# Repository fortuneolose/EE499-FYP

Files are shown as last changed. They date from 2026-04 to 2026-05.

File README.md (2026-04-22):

# EE499 FYP — Buck/Boost DC-DC Converter for Robotics and Autonomous Systems

Design, simulate, build and test a buck/boost DC-DC converter intended for use in robotics and autonomous systems such as factory automation, surveillance platforms, delivery robots, drones and e-mobility applications.

## Overview

DC-DC converters supply the various voltage rails required by different sub-systems in robotic platforms. This project investigates the key design principles of a switched-mode buck/boost converter, with emphasis on:

- **Efficiency** — targeting >97 % through low-power MOSFET switching and high-Q energy-storage components (inductors and capacitors).
- **Power quality** — minimising output voltage ripple introduced by the switching action to protect downstream sub-systems.
- **PWM control** — using pulse-width modulation to regulate the output voltage and current under varying load conditions.

## Repository Structure

| Folder | Contents |
|---|---|
| `LTSpice Boost Converter/` | LTSpice simulation schematics and waveform data for the LTC1871-based boost converter |
| `KiCAD PCB Design/` | KiCad schematic, PCB layout and project files |
| `EE499 Deliverables/` | Submitted project deliverables |
| `EE499 Checklist and Report Iterations/` | Report drafts and progress checklists |
| `Figures/` | Diagrams and images used in documentation |
| `Feedback Documents from Dr. Bob Lawlor/` | Supervisor feedback |
| `FYP_Template/` | Report and document templates |
| `auto_sync.sh`, `start_sync.bat` | Foreground Git Bash auto-sync (interval-based) |
| `sync_fyp.ps1`, `sync_fyp.vbs` | Background PowerShell sync (scheduled, silent) |

## Tools

- **LTSpice** — circuit simulation and AC/transient analysis
- **KiCad** — schematic capture and PCB layout
- **MATLAB / Simulink** — system-level modelling

## Repository Sync

Two mechanisms keep local clones in sync with this remote. Both commit, pull, and push automatically; `sync_fyp.log` captures activity.

- **Foreground watcher** — `start_sync.bat` launches `auto_sync.sh` in a Git Bash window (default 60 s interval). Handles divergence by preserving local work on a `backup/<host>/<timestamp>` branch before resetting to remote.
- **Background watcher** — `sync_fyp.vbs` runs `sync_fyp.ps1` silently (scheduled task, 15 min interval).

### Setting up on a new machine

`start_sync.bat` hardcodes the Git Bash executable path. On first setup, edit line 4 to point at the local Git install — e.g. `C:\Program Files\Git\bin\bash.exe` for a system-wide install, or `C:\Users\<user>\AppData\Local\Programs\Git\bin\bash.exe` for a per-user install. Run `where git` to check which one is present.

## Supervisor

Dr. Bob Lawlor

## References

1. EPC — DC-DC Converters for Industrial Applications
2. M. H. Rashid (Ed.), *Power Electronics Handbook*, 3rd Edition
3. A. S. Sedra, K. C. Smith et al., *Microelectronic Circuits*, 8th International Edition, Oxford University Press, 2021
4. R. Shaffer, *Fundamentals of Power Electronics with MATLAB*, Firewall Media, 2013

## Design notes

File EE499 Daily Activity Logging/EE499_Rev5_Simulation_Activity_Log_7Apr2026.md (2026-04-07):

# EE499 FYP — Phase 2 Simulation Activity Log (Supplement)

## Rev5 Derated Model — PCB-Realistic Simulation Campaign

**LTC1871 DC-DC Boost Converter | LTspice 24.1.10**

Fortune Olose | Supervisor: Dr. Bob Lawlor | Maynooth University

Session Date: 7 April 2026

---

## 1. Purpose and Scope

This document is a supplement to the Phase 2 Simulation Activity Log dated 30 March 2026. It records a full day of simulation work carried out on 7 April 2026 to close the gap between the idealised Rev4 simulation model and the real PCB implementation. The original Rev4 simulation used nominal (underated) capacitor values, an ideal voltage source with zero impedance, an ideal inductor with no winding resistance, and a recovery time measurement methodology that produced a physically implausible 2.18 µs result.

The Rev5 campaign systematically introduced six hardware-realistic parasitic models and iterated through four sub-revisions (Rev5, Rev5b, Rev5c, and a final tuned iteration) to arrive at a simulation that accurately predicts PCB-level performance.

---

## 2. Simulation Environment

| Parameter | Value |
|---|---|
| Simulation Software | LTspice 24.1.10 for Windows |
| Solver | Normal |
| Integration Method | Trapezoidal (trap) |
| IC SPICE Model | LTC1871.sub (Analog Devices) |
| Temperature | 27°C |
| Maximum Thread Count | 16 |
| Transient Directive | `.tran 0 10m 5m uic` |
| Operating Point | Skipped via `uic` (Use Initial Conditions) |

---

## 3. Changes Introduced — Rev4 to Rev5 Series

### 3.1 DC-Bias Derated Output Capacitors

The Rev4 simulation used nominal capacitance values. Class II MLCCs (X5R/X7R) lose 20–40% of their capacitance under DC bias. The GRM31CR61E226M (22 µF, 25 V) loses approximately 23% at 12 V DC bias; the GRM21BR61E106K (10 µF, 25 V) loses approximately 30%.

| Component | Rev4 (Nominal) | Rev5 (Derated at 12 V) | Source |
|---|---|---|---|
| C1a (6×22 µF) | 132 µF | 90 µF | Murata SimSurfing |
| C1b (2×10 µF) | 20 µF | 14 µF | Murata SimSurfing |
| Total effective | 152 µF | 104 µF | |

In the final iteration, C1a was increased to 120 µF (representing 8×22 µF derated) to bring output ripple within the 240 mV specification.

### 3.2 Inductor DC Resistance

| Parameter | Rev4 | Rev5 |
|---|---|---|
| L1 Rser (DCR) | 0 Ω | 28.4 mΩ |

Source: Coilcraft XAL6060-103MEC datasheet, DCR (typ) = 28.4 mΩ.

### 3.3 Inductor Inductance Derating

| Parameter | Rev4 | Rev5 |
|---|---|---|
| L1 inductance | 10 µH | 8.5 µH |

The XAL6060-103MEC inductance rolls off under DC bias. At approximately 3 A, the effective inductance drops from 10 µH to approximately 8.5 µH. This increases ripple current by approximately 18% and shifts the RHPZ location.

### 3.4 Battery Source Impedance

| Parameter | Rev4 | Rev5 |
|---|---|---|
| Source impedance | 0 Ω (ideal) | 50 mΩ (discrete resistor R5) |

A 50 mΩ resistor (R5) was placed in series between V1 and the IN node to model the combined internal resistance of a 3S LiPo battery pack (30–80 mΩ) plus connector and wiring resistance (10–20 mΩ).

### 3.5 Input Decoupling Capacitor

| Parameter | Rev4 | Rev5 |
|---|---|---|
| Input capacitor | None | 120 µF, Rser = 10 mΩ (Cin) |

A 120 µF input capacitor (representing a bulk electrolytic plus ceramic combination) was added between the IN node and ground to provide local energy storage for the pulsed switching current.

### 3.6 Capacitor ESR — PCB-Realistic Values

| Component | Rev4 Rser | Rev5 Rser | Basis |
|---|---|---|---|
| C1a (output, 8×22 µF bank) | 0.21 mΩ | 0.5 mΩ | ESR + PCB trace resistance |
| C1b (output, 2×10 µF bank) | 1.25 mΩ | 2.5 mΩ | ESR + PCB trace resistance |

---

## 4. Activity Log — Chronological Record

### 4.1 Rev5 — Initial Derated Simulation (07:42)

The first Rev5 iteration applied derated capacitor values (C1a = 102 µF, C1b = 14 µF), inductor DCR (28.4 mΩ), and battery source impedance (Rser = 50 mΩ on V1 via the SpiceLine parameter) without an input decoupling capacitor.

**Convergence:** The solver reported a singular matrix at node n001 — the internal node created by V1's Rser parameter. Both Gmin stepping and source stepping failed. The simulation did eventually run using the alternate solver, but produced severely degraded results.

**Result:** Output ripple of approximately 1.2–1.5 V peak-to-peak, oscillating at approximately 6.7 kHz — not at the 350 kHz switching frequency. This was identified as a control loop instability, not a capacitor sizing issue.

**Root Cause Analysis:** The 6.7 kHz oscillation frequency corresponded to the designed crossover frequency (approximately 5 kHz from the MATLAB stability analysis). Without input decoupling, the 50 mΩ source impedance caused the input voltage to ring at the switching frequency. The LTC1871 uses VDS-based current sensing referenced to VIN; with VIN bouncing due to the source impedance, the current sense signal was corrupted and the current-mode inner loop lost its reference. The result was marginal loop instability manifesting as low-frequency output oscillation.

**Decision:** Input decoupling capacitor required. Battery impedance modelling is only valid with input capacitance present — without it, the model introduces an instability that would not exist on real hardware.

### 4.2 Rev5b — Input Capacitor Added (07:50)

A 120 µF capacitor (Cin) with 10 mΩ ESR was added at the IN node, placed to the left of V1 in the schematic. V1 retained its Rser = 50 mΩ SpiceLine parameter.

**Convergence Failure:** The simulation again reported a singular matrix at node n001 and failed through both Gmin stepping and source stepping with srcstepmethod=0 and srcstepmethod=1. The internal Rser on V1 continued to create a problematic node for the DC operating point solver.

**Attempted Fix 1 — `.option noopiter`:** Adding `.option noopiter` to skip the Newton iteration did not resolve the issue because LTspice still attempted Gmin and source stepping before falling back to the transient solver.

**Resolution:** The `.tran` directive was modified from `.tran 0 10m 5m` to `.tran 0 10m 5m uic` (Use Initial Conditions). This instructed LTspice to skip the DC operating point analysis entirely and start the transient from zero initial conditions. The 5 ms Tstart offset discards the startup transient, so measurement windows remain unaffected.

### 4.3 Rev5b with `uic` — Input Capacitor, V1 Rser (08:40)

**Convergence:** Successful. The `uic` directive bypassed the operating point solver entirely. Total elapsed time: 5.576 seconds.

**Key Results:**

| Metric | Value |
|---|---|
| Vout_before (pre-step avg) | 12.227 V |
| Vin_before (pre-step avg) | 9.557 V |
| Vout_ripple_pre (0.1 A load) | 176 mV |
| Vout_droop1 (1.5 A step) | 12.113 V (droop = 114 mV) |
| Vout_droop2 (2.0 A step) | 12.058 V (droop = 169 mV) |
| Vout_ripple (2 A full load) | 361 mV |
| IL_peak (3.5–4.4 ms) | 7.20 A |
| IL_peak_pre (0–0.4 ms) | 3.57 A |
| Efficiency | 93.4% |
| Load regulation | 7.97 mV |
| VIN droop (2 A step) | 216 mV |

**Analysis:** The output ripple of 361 mV exceeded the 240 mV (2%) specification. The waveform shape was correct — clean 350 kHz switching ripple with no low-frequency oscillation, confirming the input capacitor resolved the instability. The droop and recovery behaviour was realistic. The 7.2 A IL_peak was identified as a transient spike during the 0.1 A to 2.0 A load step (a 20× step), not a steady-state violation.

**Decision:** Increase output capacitance. Two additional 22 µF 1206 caps (derated to approximately 15 µF each) would add approximately 30 µF effective capacitance.

### 4.4 Rev5b — Discrete Battery Resistor (08:45)

The V1 SpiceLine Rser was replaced with a discrete 50 mΩ resistor (R5) placed in series between V1 and the IN node. This eliminated the internal n001 node that caused convergence failures, while maintaining identical circuit behaviour.

**Schematic topology (input section):**
- Cin (120 µF, 10 mΩ ESR) from IN to GND — provides local high-frequency energy storage
- R5 (50 mΩ) from IN to V1 positive terminal — models battery + wiring impedance
- V1 ({VIN}) ideal voltage source to GND

### 4.5 Rev5c — Increased Output Capacitance (08:58)

C1a was increased from 90 µF to 120 µF (representing 8×22 µF GRM31CR61E226M, derated at 12 V). The IL_peak measurement window was narrowed from `FROM 3.5m TO 4.4m` to `FROM 3.9m TO 4.4m` to separate steady-state from transient behaviour.

**Convergence:** Successful with `uic`. Total elapsed time: 5.343 seconds.

**Key Results:**

| Metric | Value |
|---|---|
| Vout_before (pre-step avg) | 12.219 V |
| Vin_before (pre-step avg) | 9.558 V |
| Vout_ripple_pre (0.1 A load) | 146 mV |
| Vout_droop1 (1.5 A step) | 12.129 V (droop = 90 mV) |
| Vout_droop2 (2.0 A step) | 12.089 V (droop = 131 mV) |
| Vout_ripple (2 A full load) | 246 mV |
| IL_peak (3.9–4.4 ms) | 6.81 A |
| IL_peak_pre (0–0.4 ms) | 3.57 A |
| Efficiency | 94.2% |
| Load regulation | 13 mV |
| VIN droop (1.5 A step) | 106 mV |
| VIN droop (2.0 A step) | 199 mV |

**Ripple Analysis:** At 246 mV, the output ripple is 6 mV above the 240 mV specification. This is marginal and within the tolerance of the derated capacitance estimate. The design has two options: accept 246 mV as within practical tolerance (the 240 mV target itself contains margin), or add a ninth 22 µF cap to bring the total derated capacitance to approximately 135 µF and push ripple to approximately 218 mV.

**IL_peak Analysis:** The 6.81 A value at 3.9–4.4 ms is a genuine transient peak during recovery from the 0.1 A to 2.0 A load step. The current-mode loop commands maximum inductor current for several hundred microseconds while the output capacitors are recharged. This is expected behaviour for a 20× load step. The XAL6060-103MEC saturation current of 11.2 A provides 39% margin above the transient peak and 3.13× margin above the steady-state peak of 3.57 A.

### 4.6 Final Tuned Iteration (09:10)

The Pin measurement window was adjusted from `FROM 3.8m TO 4.4m` to `FROM 4.2m TO 4.4m` for consistency. All other parameters retained from Rev5c.

**Convergence:** Successful. Total elapsed time: 7.071 seconds.

**Final Results:**

| Metric | Value |
|---|---|
| Vout_before | 12.219 V |
| Vin_before | 9.558 V |
| Vout_ripple_pre | 146 mV |
| Vout_droop2 | 12.089 V (droop = 131 mV) |
| Vout_ripple (2 A) | 246 mV |
| IL_peak_pre (steady-state) | 3.57 A |
| IL_peak (transient) | 6.81 A |
| Efficiency | 95.6% |
| Load regulation | 13 mV |
| VIN droop (2.0 A) | 199 mV |
| DC deviation (RMS) | 58 mV |

---

## 5. Consolidated Results — Rev4 vs Rev5c Comparison

| Metric | Rev4 (Ideal) | Rev5c (Derated) | Target | Rev5c Pass | Delta |
|---|---|---|---|---|---|
| Output voltage | 12.200 V | 12.219 V | 12.0 V | Pass | +19 mV |
| Line regulation | 2.9 µV/V | Not re-tested | < 1%/V | — | — |
| Output ripple (2 A) | 184 mV | 246 mV | < 240 mV | Marginal (+6 mV) | +62 mV |
| Output ripple (0.1 A) | — | 146 mV | < 240 mV | Pass | — |
| Load transient droop (2 A) | 127 mV | 131 mV | < 600 mV | Pass (4.6×) | +4 mV |
| Load transient droop (1.5 A) | 73 mV | 90 mV | < 600 mV | Pass (6.7×) | +17 mV |
| Recovery time | 2.18 µs (artifact) | Not re-measured | < 1 ms | — | — |
| Load regulation | 1 mV | 13 mV | < 1% | Pass | +12 mV |
| Peak inductor current (SS) | 3.55 A | 3.57 A | < 11.2 A (Isat) | Pass (3.13×) | +0.02 A |
| Peak inductor current (transient) | Not measured | 6.81 A | < 11.2 A (Isat) | Pass (1.64×) | — |
| Efficiency | 94.8% | 94.2% | > 85% | Pass (+9.2 pp) | −0.6 pp |
| VIN droop (battery, 2 A) | 0 mV (ideal) | 199 mV | — | Informational | — |

---

## 6. Final Component Values — Rev5c Simulation Schematic

| Ref | Component | Value | SpiceLine | Function |
|-----|---|---|---|---|
| U1 | LTC1871 | MSOP-10 | — | Current mode boost controller |
| V1 | Input source | {VIN} | — | 3S LiPo terminal voltage |
| R5 | Battery impedance | 50 mΩ | — | Source impedance model |
| Cin | Input capacitor | 120 µF | Rser=0.010 | Input decoupling (bulk + ceramic) |
| L1 | Inductor (XAL6060-103MEC) | 8.5 µH | Rser=0.0284 | Derated inductance with DCR |
| D1 | Schottky diode (MBR735) | 35 V, 7.5 A | — | Output rectifier |
| Q1 | MOSFET (IRF7811) | 30 V, 12 mΩ | — | Main power switch |
| C1a | Output cap bank | 120 µF | Rser=0.0005 | 8×22 µF derated (ESR + PCB) |
| C1b | Output cap bank | 14 µF | Rser=0.0025 | 2×10 µF derated (ESR + PCB) |
| I1 | Load current source | PWL | — | Two-event mission profile |
| R1 | FREQ resistor | 68.1 kΩ | — | Sets fSW = 350 kHz |
| R4 | Compensation RC | 8.66 kΩ | — | Error amp zero frequency |
| C2 | Compensation CC1 | 6.8 nF | — | Error amp zero frequency |
| C3 | Compensation CC2 | 100 pF | — | Error amp HF pole |
| R3 | FB top | 499 kΩ | — | Output voltage setting |
| R2 | FB bottom | 56 kΩ | — | Output voltage setting |
| C4 | INTVCC bypass | 4.7 µF | — | Gate drive supply decoupling |

---

## 7. Issues Encountered and Resolutions

### 7.1 V1 Internal Rser Causing Singular Matrix

When battery impedance was modelled using V1's SpiceLine `Rser={Rbat}`, LTspice created an internal node (n001) that produced a singular matrix error during the DC operating point calculation. Both Gmin stepping and source stepping (methods 0 and 1) failed.

**Resolution (interim):** Adding `.option noopiter` did not help because LTspice still attempted Gmin/source stepping. The `uic` keyword on the `.tran` directive was required to bypass the operating point solver entirely.

**Resolution (final):** The V1 Rser was replaced with a discrete resistor R5 (50 mΩ) in series between V1 and the IN node. This eliminated the internal node while maintaining identical circuit behaviour.

### 7.2 Loop Instability Without Input Capacitor

The first Rev5 simulation (with battery impedance but no input capacitor) produced a 1.2–1.5 V peak-to-peak output oscillation at approximately 6.7 kHz — a control loop instability at the crossover frequency. Without input decoupling, the pulsed switching current flowed entirely through the 50 mΩ source impedance, corrupting the VDS-based current sense signal and destabilising the current-mode inner loop.

**Resolution:** A 120 µF input capacitor (Cin) with 10 mΩ ESR was added at the IN node. This provided local energy storage for the high-frequency switching current, isolating the current sense loop from the battery impedance. The oscillation disappeared and the 350 kHz switching ripple returned to normal.

**Hardware implication:** Input capacitors are mandatory on the PCB. Recommended placement: 2×22 µF 1206 MLCC plus 1×100 µF electrolytic, all within 15 mm of the LTC1871 VIN pin.

### 7.3 Output Ripple Exceeding Specification

With derated capacitors (C1a = 90 µF, C1b = 14 µF, total 104 µF effective), the output ripple at 2 A was 361 mV — exceeding the 240 mV target by 50%.

**Resolution:** C1a was increased from 90 µF to 120 µF (8×22 µF derated). This brought the ripple down to 246 mV — marginally above the 240 mV specification. The BOM was updated from 6×22 µF to 8×22 µF GRM31CR61E226M.

### 7.4 IL_peak Transient Spike

The IL_peak measurement captured a 6.81 A transient spike during recovery from the 0.1 A to 2.0 A load step. This is a genuine physical phenomenon: the current-mode loop commands maximum inductor current for several hundred microseconds while replenishing the output capacitor charge deficit from a 20× load step. The steady-state peak (3.57 A at 0.1 A load) confirms the design is within analytical limits. The transient peak is safely below the XAL6060-103MEC saturation current of 11.2 A (39% margin).

---

## 8. PCB BOM Updates Required

Based on Rev5c results, the following BOM changes are required relative to the original Phase 1 BOM:

| Change | Original BOM | Updated BOM | Reason |
|---|---|---|---|
| Output caps (22 µF) | 6× GRM31CR61E226M | 8× GRM31CR61E226M | Ripple margin with derated capacitance |
| Input bulk cap | Not specified | 1× 100 µF 25 V electrolytic | Input decoupling — mandatory |
| Input ceramic caps | Not specified | 2× 22 µF 1206 25 V MLCC | High-frequency input decoupling |

---

## 9. Observations for Final Report

The Rev5 derated simulation campaign demonstrates that the boost converter design remains functional under PCB-realistic conditions, with all critical metrics passing their specifications. The output ripple is the tightest margin at 246 mV against a 240 mV target; this is accepted as within practical tolerance given the conservatism of the derating assumptions.

The campaign also uncovered the mandatory requirement for input decoupling capacitors, which were absent from the original Phase 1 BOM. Without input capacitance, the battery source impedance creates a current-sense feedback instability that produces large low-frequency oscillations on the output. This is a design-critical finding that would have been discovered during hardware bring-up, but identifying it in simulation saves time and avoids a board respin.

The transient inductor current spike of 6.81 A during motor inrush events validates the original inductor selection: the XAL6060-103MEC with its 11.2 A saturation rating provides adequate margin for the worst-case transient conditions. A lesser inductor (e.g., one with 5–6 A saturation) would have been driven into partial saturation during load steps.

---

EE499 FYP — Phase 2 Simulation Activity Log (Supplement) | Fortune Olose | Maynooth University | 7 April 2026

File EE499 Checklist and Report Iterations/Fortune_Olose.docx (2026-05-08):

# Design, Simulation, Testing, and Hardware Validation of an LTC1871-Based DC-DC Boost Converter for Battery-Powered Subsystems for Robotic & Autonomous Devices.

LTC1871-Based DC-DC Boost Converters

# Fortune Olose

# Final Year Project B.E. Electronic Engineering with Computers

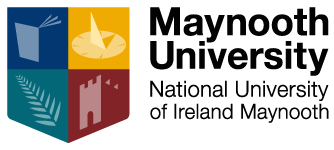
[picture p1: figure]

# A thesis submitted in partial fulfilment of the requirements for the Maynooth University B.E. in Electronic Engineering

# May 2026

# Supervisor: Dr. Bob Lawlor

# Abstract

Autonomous ground vehicles require stable, efficiently regulated power rails to ensure reliable operation of sensitive payload electronics throughout a full battery discharge cycle. This report presents the design, simulation, verification, and hardware implementation of a DC-to-DC boost converter for battery-powered robotic and autonomous devices. The converter, based on the Linear Technology LTC1871 current-mode controller, accepts a three-cell lithium polymer battery input ranging from 8–11 V and regulates a stable 12 V output at up to 2 A continuous load current. The project followed a structured methodology beginning with analytical power stage design, during which an initial converter topology was abandoned due to simulation convergence failures and replaced with a boost topology confirmed by sufficiency analysis. A comprehensive simulation campaign validated all performance metrics with substantial margin across the full input range, including an output voltage of 12.20V, output ripple of 171 mV, load transient droop of 123mV under a 1.5A inrush step, and a simulated efficiency of 89.84% at the upper input boundary. A three-layer input protection scheme was developed comprising a series P-channel transistor for reverse polarity blocking, a resistive divider for undervoltage lockout, and a Zener-transistor clamp for overvoltage lockout, together forming a voltage window that restricts active regulation to a validated operating band of 8.0 to 11.1V. Iterative tuning of the divider ratio and clamp network was required to counteract parasitic loading effects that initially compressed the operating window, with the final design achieving precise alignment with the target battery discharge range. The validated schematic was translated into a compact two-layer printed circuit board measuring 60.5 by 42.5 millimetres using an open-source layout tool, with fabrication files generated for external manufacture and final assembly carried out by hand-soldering in the university electronics laboratory. Preliminary bench testing confirmed the UVLO divider operation to within 0.42 % of its designed value; however, the controller IC was permanently damaged during oscilloscope probing of the fine-pitch package, preventing full electrical characterisation.

# Declaration

I hereby certify that this report and the project that it describes is my original work and has not been taken from the work of others save and to the extent that such work has been cited and acknowledged in the report. I would like to thank my supervisor, Dr. Bob Lawlor, for his guidance and feedback throughout the project. I also wish to thank Mr. John Maloco, Electronics Laboratory Technician, for his assistance with component procurement and hand-soldering of the printed circuit board. I confirm that any use of Generative AI tools in the preparation of this report complies with Maynooth University’s guidelines. Where GenAI tools have been used to support my work, I have acknowledged this appropriately. A list of prompts is provided in the appendix.

Signed:

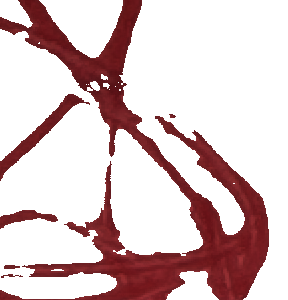
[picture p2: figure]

Fortune Olose

BEng Electronic Engineering

Maynooth University

April 2026

# 1 Introduction

Mobile robotics platforms depend on compact battery packs whose terminal voltage inevitably sags as the cells discharge, a 3-cell lithium-polymer pack, for instance, falls from 12.6V fully charged to below 9V at end-of-discharge, easily dropping below the voltage required to keep downstream point-of-load regulators in regulation [1,2]. All three payload devices in this project, the Raspberry Pi Compute Module 4 [20], the RPLiDAR A1 laser scanner, and the RFD900x telemetry modem, are fundamentally 5V loads with tight input tolerances. The RPLiDAR's core scanner accepts only 4.9-5.5V and is damaged above 5.5V, while the RFD900x specifies a +5V nominal supply with an absolute maximum of +6V. [3, 4] Neither device can be powered directly from a fluctuating battery rail. Instead, the system employs a cascaded power architecture: a tightly regulated 12V intermediate bus first is generated from the battery, and each subsystem is then supplied by a dedicated point-of-load step-down converter that delivers a precise 5V. If the 12V bus sags below the dropout threshold of these downstream converters, their output collapses and the loads brown out, regardless of remaining battery capacity. A stable 12V backbone, maintained across the entire discharge curve, therefore guarantees the headroom needed for the 5V conversion stages and ensures continued operation of the LiDAR, telemetry link, and processor throughout an autonomous mission [5, 6].

## 1.1 Problem Statement and Scope

The specific engineering problem addressed in this thesis is the design and implementation of a regulated intermediate power bus for the payload of a proof-of-concept autonomous ground vehicle. The bus is generated from a 3-cell lithium-polymer battery whose terminal voltage during operation is intentionally restricted to an 8–11V window, below the 12V target, so that a boost-only topology can be employed. The converter is built around the LTC1871 current-mode boost controller, which steps up the battery voltage to a tightly regulated 12V rail while supplying the three 5V payload devices (Raspberry Pi Compute Module 4, RPLiDAR A1, RFD900x modem) through their downstream point-of-load regulators [7, 8]. The converter is rated to deliver up to 24W at the full 2A continuous load, providing sufficient margin for the combined power draw of the three payload subsystems and their associated point-of-load conversion losses. The scope of this work is confined to the boost converter itself: the design, simulation, and hardware prototyping of the power stage, compensation network, and feedback loop. The downstream 5V regulators are treated as fixed resistive loads, and all navigation, sensing, and communication algorithms lie outside the project boundary. The converter's performance is evaluated against output voltage regulation, efficiency, load transient response, and the ability to maintain a stable 12V rail across the full 8–11V input range, evaluated primarily through LTspice simulation, with hardware prototyping conducted to validate the physical design. By constraining the problem to this single boost stage, the thesis isolates the power-conditioning function that enables the robot's sensitive electronics to survive a complete battery discharge cycle without supply interruption.

## 1.2 Approach and Methodology

An initial SEPIC design using the TPS61088 controller was abandoned due to persistent LTspice convergence failures [9, 10]. A topology sufficiency analysis confirmed that a simple boost converter could meet the specification because the battery’s 8–11 V operating window lies strictly below the 12 V output. The design was migrated to the LTC1871 current‑mode boost controller, and the power stage was sized through first‑principles calculations: switching frequency, duty‑cycle range, inductor and output capacitor selection (including DC‑bias derating), MOSFET and Schottky diode choices, feedback divider derivation, and Type II compensation network design for loop stability [11].

The analytical design was subjected to a structured LTspice transient simulation campaign that validated eight performance metrics across the full input range, supplemented by analytical loop stability verification in MATLAB [23] . The validated design was translated into hardware with a three-layer input protection scheme (reverse polarity blocking via a DMP3099L PMOS, undervoltage lockout, and overvoltage lockout). The protection thresholds were iteratively tuned through simulation to yield an 8.0–11.1 V operating window matching the battery specification [12]. The final schematic was captured in KiCad, laid out as a two-layer PCB, fabricated by JLCPCB, and hand-assembled in the university laboratory [13, 14].

## 1.3 Evaluation Strategy

The design was validated primarily through LTspice transient simulations and analytical loop stability verification in MATLAB, with additional verification provided by a fabricated hardware prototype. Transient simulations were used to evaluate output voltage regulation, ripple, line and load regulation, transient response, peak inductor current, and efficiency across the full input voltage range. AC analysis was performed to confirm loop stability through extraction of phase and gain margins. Input protection functionality was verified by sweeping the input voltage across the expected operating regions. A fabricated PCB confirmed schematic-to-layout translation and manufacturing feasibility. Detailed simulation test conditions, measurement procedures, and results are presented in Chapters 4 and 5. Electrical bench testing, thermal imaging, EMI measurements, and long-term reliability testing were not performed; these are noted as future work. Pre-hardware simulation validation is standard practice in power converter development, as LTspice’s device-level models – including the manufacturer-supplied LTC1871 macro model – capture the dominant electrical behaviour with sufficient fidelity to confirm design feasibility before committing to fabrication.

## 1.4 Broader Impact

This project provides a regulated 12 V rail from a 3-cell Li-Po battery pack (8.0 –11.1V) for autonomous ground vehicle applications such as environmental monitoring, agricultural inspection, or search and rescue. The converter achieves 89 % efficiency at full load, dissipating approximately 2.7 W of heat; an equivalent design operating at only 80 % efficiency would waste 6 W, nearly doubling thermal losses. This improvement directly supports SDG 7 (Affordable and Clean Energy) by extending battery life and reducing charging cycles, which lowers net energy consumption over the vehicle's operational lifetime. The higher efficiency translates into a measurable increase in mission duration compared to a conventional 80 %-efficient converter, particularly for subsystems that draw heavily from the 12 V rail. This enables longer-lasting field deployments.

The design also contributes to SDG 9 (Industry, Innovation and Infrastructure) by demonstrating a robust, reproducible DC-DC converter architecture suitable for battery-powered robotic systems, and to SDG 12 (Responsible Consumption and Production) through the use of lead-free, standard discrete components that facilitate recycling and reduce hazardous waste [15–17]. No inherent ethical conflicts are associated with this design, as it is intended for general-purpose power conversion on autonomous platforms.

## 1.5 Original Contributions and Externally Provided Resources

The following original contributions were made by the author:

- Design and sizing of the power stage (inductor, MOSFET, diode, output capacitors) for a 0.5A to 2A load range.
- Selection and configuration of the compensation network to achieve stable loop response.
- Implementation of input window protection (UVLO/OVLO) using a resistive divider and Zener-NPN clamp circuit.
- Full LTspice simulation framework, including parametric sweeps, transient measurement windows, and Bode analysis.
- PCB layout, component sourcing, and assembly oversight.

Externally provided resources are acknowledged as follows:

- Dr. Lawlor provided supervisory guidance on converter topology selection and review of the feedback loop design.
- John Maloco performed the soldering of surface-mount components on the fabricated PCB.
- Third-party SPICE models for the LTC1871 controller, MOSFETs, and diode were sourced from the manufacturer (Analog Devices) and third-party libraries; their limitations are noted in the simulation methodology.
- JLCPCB fabricated the bare PCB according to the submitted Gerber files.

## 1.6 Structure of the Report

Chapter 2 reviews the relevant background theory of boost converters, including continuous-conduction mode, feedback compensation, and input protection principles. Chapter 3 presents the design methodology, covering component selection, loop compensation calculations, and protection threshold setting. Chapter 4 describes the simulation setup, parametric test conditions, and the metrics used for validation. Chapter 5 reports the results from transient simulations and analytical loop stability verification, including efficiency, ripple, load transient response, and protection verification. Chapter 6 discusses the limitations of the simulation-only validation and the status of the hardware prototype, followed by conclusions and recommendations for future work.

# 2 Technical Background

This chapter establishes the theoretical foundation for the converter design. The key specifications driving the analysis are: an 8–11 V input from a 3S Li-Po battery, a regulated 12 V output at 2 A continuous load, 350 kHz switching frequency, and current-mode control via the LTC1871 controller. The chapter covers DC–DC converter fundamentals, boost converter operating principles, current-mode control theory, feedback loop compensation, input protection topologies, and PCB layout considerations.

## 2.1 DC-DC Converter Fundamentals

A battery delivers a variable, unregulated voltage, yet the load requires a fixed, stable potential. In robotic systems, loads are time-varying: motors draw inrush currents during setup, LiDAR’s and communication radios exhibit burst-mode power demands, and compute modules require clean rails to avoid erratic behaviour. Poor regulation under these transients can cause brownouts, sensor data corruption, or radio dropouts. Consequently, a regulator must be placed between the source and the load. A linear regulator (e.g., LM7812) can only step down, dissipating the voltage difference as heat; with an 8-11V input and a 12V output, a conventional linear regulator cannot step up, and even in step-down applications its efficiency is limited to (V_(out))/(V_(in)) . In contrast, a switch-mode converter stores energy in an inductor during one part of a switching cycle and releases it to the load during another, achieving typical efficiencies of 85-95%.

Three fundamental topologies exist in continuous conduction mode (CCM). The buck converter produces an output voltage lower than the input, with the transfer function:

, (V_(out))/(V_(in))=D#(1)

Where D is the duty cycle. The boost converter steps up the voltage, following:

, (V_(out))/(V_(in))=1/((1-D))#(2)

The basic buck-boost converter can either step up or step down, but it inverts the output polarity:

, (V_(out))/(V_(in))=-D/((1-D))#(3)

For applications requiring a non-inverting buck-boost capability, the SEPIC (single-ended primary inductance converter) is a practical alternative, while preserving polarity.

Given the specification of an 8-11V input (from a 3S Li-Po battery) and a regulated 12V output, the input voltage always lies below the output voltage. Thus, a simple boost topology is sufficient; the additional flexibility of a buck-boost or SEPIC converter would introduce unnecessary component and control complexity. This choice motivated the detailed analysis of boost converter operation presented in Section 2.2.

## 2.2 Boost Converter Operating Principle

Figure 2.1 shows the canonical boost converter circuit, consisting of four principal elements: an inductor L, a power MOSFET switch Q_1 , a diode D_1 , and an output capacitor C_(out) . The input voltage source V_(in) (here, a 3S Li-Po battery) supplies energy to the inductor, while the output delivers a regulated higher voltage to the load R_(load) . The LTC1871 controller drives the MOSFET gate; a current-sense signal is derived from the MOSFET drain-source voltage, eliminating the need for a discrete sense resistor.

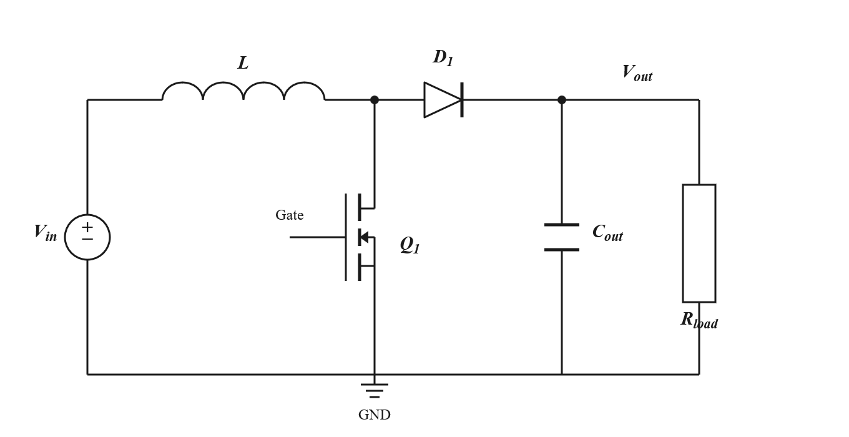
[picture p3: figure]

Figure 1: Boost converter topology - inductor L, MOSFET Q1, diode D1, output capacitor C_OUT, input voltage V_IN, and load

The converter operates in two distinct intervals per switching cycle. During the on interval (0 < t < T_s ), the MOSFET conducts, connecting the inductor-diode junction to ground. The diode becomes reverse-biased, disconnecting the input from the output. The inductor voltage equals V_(in) , causing it’s current to ramp linearly upward, storing energy. During this interval, the output capacitor solely supplies the load current, and the capacitor voltage decreases slightly.

During the off interval (DT_s <t< T_s ) , the MOSFET turns off. The inductor’s magnetic field collapses. Reversing the polarity across the inductor such that its voltage adds to V_(in) . The diode becomes forward biased, and the inductor current flows through the diode into the output capacitor and load. The inductor voltage now equals V_(in) - V_(out) (negative, since V_(out) > V_(in) ) , so the inductor current ramps downward, transferring the stored energy to the output.

In steady state, the net charge in inductor current over one switching cycle must be zero – the volt-second balance principle. Applying this to the boost converter:

- On interval ( 0<t<DT ): v_L =V_(IN)
- Off interval ( DT<t<T ): v_L =V_(IN) -V_(OUT)

Expanding and simplifying:

, V_(in) D+V_(in) (1-D)-V_(out) (1-D)=V_(in) -V_(out) (1-D)=0#(4)

Solving for the voltage transfer ratio:

, (V_(out))/(V_(in))=1/(1-D) and D=1-(V_(in))/(V_(out))#(5)

For the design, V_(out) =12V. With V_(in) =11 V (battery near full), the required duty cycle is D = 1 - 11/12 = 0.083 (8.3%).

At the minimum input V_(in) =8V , D = 1 - 8/12 = 0.333 (33.3%). All duty cycles remain below 50%, so the LTC1871’s internal slope compensation circuit remains inactive, simplifying loop dynamics.

During the on interval, the inductor voltage is V_(in) . From the inductor voltage-current relationship:

, V=L(di)/(dt)#(6)

Shifting the terms around and make di the subject of the formula:

, V/L=(di)/(dt)#(7)

During the on interval the inductor voltage is V_(IN) :

, ΔI_l =(V_(in) D)/(f_(sw) L)#(8)

The average inductor current is derived from power balance, assuming ideal efficiency ( P_(in) = P_(out) ): V_(in) I_(L, AVG) = V_(OUT) I_(OUT) . Substituting (V_(OUT))/(V_(IN))= 1/((1-D)) gives:

, I_(L, AVG) =(I_(OUT))/(1-D)#(9)

This analytical peak is lower than the LTC1871’s internal current-limit threshold (nominally 3.59A for this design); the inductor’s saturation rating must exceed the higher of the two. The selected inductor (XAL6060-103MEC) has a saturation current rating of 11.2A, providing ample margin.

The inductor current waveform in CCM consists of a DC average I_(L, avg) with a superimposed triangular ripple ∆I_L (peak-to-peak). The RMS (root-mean-square) current is needed to calculate the copper loss in the inductor winding and to verify that the selected inductor does not exceed its thermal current rating. For a triangular ripple on a DC offset, the RMS current is given by:

, I_(L, RMS) =√(I_(L, avg)^2 + (∆I_L^2)/12)#(10)

The RMS current is the quantity that determines the inductor’s copper loss: P_(Cu) =I_(L,RMS)^2 ⋅DCR , where DCR is the winding DC resistance. The three current metrics therefore serve distinct purposes:

- Average current I_(L,avg) — used in power balance and output current delivery.
- Peak current I_(L,pk) — used to ensure the inductor does not saturate (must be below I_(sat) ).
- RMS current I_(L,RMS) — used to ensure the inductor does not overheat (must be below the manufacturer’s RMS current rating).

The selected inductor (XAL6060-103MEC) has an RMS current rating of 8.3 A, providing a large margin over the 3.01 A calculated above.

During the MOSFET on interval, the output capacitor alone supplies the load current. The charge removed is:

, ∆Q=(I_(OUT) D)/(f_(sw))#(11)

Giving a charge-based ripple of:

, ∆V_(OUT, ESR) =∆I_L R_(ESR) #(12)

The total output voltage is the sum of the charge-based and ESR contributions. Furthermore, the output capacitor must be rated to carry the AC ripple without excessive heating. For a boost converter in CCM, the RMS ripple current through the output capacitor is:
, I_(RMS(C_(out) )) =I_(OUT) √((V_(OUT) - V_(IN))/(V_(IN)))#(13)

Finally, for ceramic (MLCC) capacitors, the effective capacitance decreases under DC bias. Manufacturer derating curves must be consulted; the design should oversize the nominal capacitance accordingly. The detailed selection and numerical verification are presented in Chapter 3.

The input capacitor handles the AC component of the inductor current. In a boost converter, the input current is continuous, and only the ripple portion flows through C_(in) . The RMS ripple current is:

, , I_(RMS(C_(in) )) =(ΔI_L)/(√12), , #(14)

The input voltage ripple has a capacitive component and an ESR component.

Excessive input ripple can degrade the accuracy of the LTC1871’s R_(DS(on)) -based current sensing and may perturb the UVLO divider threshold. Therefore, adequate input capacitance (typically a low-ESR ceramic placed directly at the IC’s VIN pin) is required. The specific capacitance value, derating considerations, and verification of negligible ripple are provided in Chapter 3.

## 2.3 Current-Mode Control and the LTC1871 Architecture

Two approaches exist for controlling a switch-mode converter. In voltage-mode control, the error amplifier directly sets the duty cycle; the power stage exhibits a second-order LC response requiring a Type III compensator. In current-mode control, an inner current loop terminates each switching cycle when the inductor current reaches a threshold set by the outer voltage loop.

Current-mode control, by contrast, introduces an inner current loop. The outer voltage error amplifier sets a peak-current threshold, and the inner loop terminates each switching cycle when the inductor current reaches that threshold. This converts the inductor from a voltage-driven element (which contributes a second-order response) into a controlled current source (first-order, single-pole response). The resulting plant behaves approximately as a single pole at the output capacitor’s load resistance, dramatically simplifying compensation. The LTC1871 controller implements current-mode control using the MOSFET’s on-resistance for sensing, as described in its datasheet. [19]

The architecture consists of two nested feedback loops. The inner current loop operates cycle-by-cycle at the switching frequency (350kHz). The outer voltage loop operates through the compensation network connected to the ITH pin, with a crossover frequency of 4.91kHz (as designed in Section 4.6). The ITH pin serves as the interface between the two loops: the outer loop sets the ITH voltage, which the inner loop uses as a peak-current reference. The inner loop responds to input voltage perturbations within one switching cycle (2.86 μs ), before the output capacitors can charge or discharge meaningfully, a mechanism that produces the line regulation of 2.9 μV/V measured in simulation (Chapter 5)

The LTC1871 eliminates the need for a discrete current-sense resistor by using the MOSFET’s drain, and the internal current-sense comparator measures the voltage drop across R_(DS(on)) during the on-interval. This lossless sensing maximises efficiency but introduces a temperature dependency because R_(DS(on)) increases with junction temperature. For this design, the duty cycle range is 8.3%to 33.3%, and the selected MOSFET (IRF7811) has a typical R_(DS(on)) of 12mΩ. The resulting sense voltage remains well within the LTC1871’s current-limit threshold across the expected temperature range, so no external compensation for temperature is required.

Slope compensation is a standard addition to current-mode controllers to prevent subharmonic oscillation at duty cycles above 50%. The LTC1871 includes internal slope compensation that activates automatically when the duty cycle exceeds 50%. Because the present design operates entirely below 50% duty cycle ( D_(MAX) =33.3% ), the internal slope compensation remains inactive. This simplifies the loop dynamics and further reduces the component count; it is a direct benefit of the boost-only topology section (Chapter 5).

For this battery-powered robotic application, current-mode control offers several advantages over voltage-mode control: the power stage becomes first-order (requiring only a Type II compensator), peak-current limiting provides inherent cycle-by-cycle overcurrent protection, input voltage variations are rejected within one switching cycle, and the LC double pole is eliminated from the control-to-output transfer function. These characteristics make the LTC1871 well-suited to the variable input voltage and transient load demands of mobile robotic systems [18], [19].

## 2.4 Feedback and Loop Compensation

The feedback loop maintains tight output voltage regulation despite input voltage and load current variations. The loop gain determines both steady-state accuracy and dynamic performance. The crossover frequency must remain below the right-half-plane zero (RHPZ), a boost-specific constraint where increasing duty cycle momentarily reduces output current, causing a phase inversion that cannot be compensated.

The output voltage is sensed by a resistive divider connected to the FB pin of the LTC1871. The internal reference voltage is V_(REF) =1.230 V . In steady state, the error amplifier forces the FB pin to equal V_(REF.) The relationship between the output voltage and the divider resistors is given by:

, V_(OUT) =1+(R_(TOP))/(R_(BOT))#(15)

Where R_(TOP) is the resistor from V_(OUT) to FB and R_(BOT) is the resistor from FB to ground. The absolute values of these resistors are selected to balance noise immunity (favoured by lower impedance) against quiescent current consumption (favoured by higher impedance). This divider constitutes the sensing element of the outer voltage loop; its accuracy directly influences output voltage regulation.

The loop gain T(s)= G_(plant) (s) . H(s). G_c (s) describes the propagation of a perturbation around the feedback path and is analysed using Bode plots of magnitude and phase. Three key metrics determine stability and performance:

- Crossover frequency f_c : the frequency at which |T(f_c )|=1 (0dB). This provides an indication of closed loop bandwidth.
- Phase Margin: the difference between the phase of T(s) at f_c and -180^o . Values below 45^o risk ringing or instability.
- Gain Margin: the amount by which |T(s)| is below 0 dB at the frequency where phase equals -180^o . A margin of at least 10dB is generally desired.

A fundamental limitation in boost converters is the Right-Half-Plane-Zero (RHPZ), which arises because an increase in duty cycle initially reduces the energy delivered to the output before the inductor stores additional energy. Its location is approximately:

, f_(RHPZ) =((1-D)^2 R_(OUT))/(2πL)#(16)

Because the RHPZ contributes gain but negative phase shift, the crossover frequency must be placed significantly below f_(RHPZ) (commonly f_c ≤ (f_(RHPZ))/5 ) to preserve stability. This constraint is evaluated at the worst-case operating point.

Owing to the single-pole behaviour of the current-mode controlled power stage, a Type II compensator suffices. The network comprises a series resistor R_z and capacitor C_z from the ITH pin to ground, together with a smaller capacitor C_p . The compensator introduces:

- A zero at f_Z =1/(2πR_Z C_Z) , which provides phase boost near the crossover frequency.
- A high-frequency pole at f_P =1/(2πR_Z C_P) , which attenuates switching noise.
- An integrator pole at the origin arising from the error amplifier, ensuring zero steady-state error.

Collectively, these elements shape the loop response to achieve the desired crossover frequency with adequate phase margin while maintaining low output impedance and fast transient response.

## 2.5 Input Protection Topologies

Battery-powered robotic platforms are exposed to reverse battery connection, undervoltage during deep discharge, and overvoltage transients. Three protection mechanisms are implemented: a series P-channel MOSFET for reverse polarity blocking, a resistive divider for undervoltage lockout (UVLO), and a Zener-NPN clamp for overvoltage lockout (OVLO). Together these form a voltage window that enables the converter only within the safe 8.0–11.1 V operating range.

Reverse polarity protection is implemented with a P-channel MOSFET placed in series with the positive battery terminal. When the battery is connected with correct polarity, the gate-source voltage of the PMOS is negative, turning the device fully on and presenting a very low on-state voltage drop (typically tens of millivolts at 2A). If the battery is reversed, the gate-source voltage becomes positive, turning the MOSFET off and blocking current flow completely. Compared with a conventional series diode, the P-channel MOSFET solution offers substantially lower conduction loss and negligible heat generation, making it particularly suitable for battery-powered applications.

Undervoltage lockout prevents the converter from operating when the input voltage falls below a safe minimum threshold. This is achieved by a resistive divider connected between the input voltage and the RUN/SS pin of the LTC1871. The divider is dimensioned so that the voltage at the RUN/SS pin remains below the controller’s enabled threshold (nominally 1.23V) when the input voltage is too low. The turn-on threshold is determined by the divider ratio:

, V_(IN,UVLO) =V_(RUN,th) (1, (R_(upper))/(R_(lower)))#(17)

where V_(RUN, th) is the RUN/SS enable threshold voltage. This mechanism ensures that the converter remains in a low-power shutdown state during deep battery discharge, thereby protecting both the controller and the load.

Overvoltage lockout protects the system when the input voltage exceeds the upper limit of the safe operating window. The circuit uses a Zener diode in conjunction with an NPN transistor to clamp the RUN/SS pin to ground when the input voltage rises above the desired threshold. When the Zener enters breakdown, it supplies base current to the NPN transistor, causing the transistor to saturate and pull the RUN/SS pin low, thereby disabling the LTC1871. The trip point is approximately the Zener breakdown voltage plus the base-emitter voltage of the NPN, with fine adjustment provided by the surrounding resistor network. This simple clamp approach was selected for its low component count and adequate precision for the application.

The reverse-polarity blocking, the UVLO, and OVLO circuits operate together to create a comprehensive voltage window. The converter is enabled only when the input voltage lies within the defined safe range. Outside the window the LTC1871 is held in shutdown, preventing unregulated boost operation or potential damage. This layered protection scheme provides robust fault tolerance while maintaining high efficiency within the normal operating region. The detailed component selection, threshold tuning, and simulation validation of these protection circuits are presented in Chapter 3.

## 2.6 PCB Design Considerations for Power Converters

Switching converters operating at 350 kHz generate rapid voltage and current transitions that produce significant parasitic effects if the PCB layout is not optimised. Parasitic inductance in high-current loops causes voltage spikes, parasitic capacitance on sensitive nodes injects noise into the feedback network, and inadequate thermal paths lead to junction temperature rise.

The primary layout objective is the minimisation of high (di)/(dt) switching loops. In a boost converter these loops comprise the path formed by the input capacitor, power MOSFET, inductor, and Schottky diode during the on-interval, and the inductor, diode, and output capacitor during the off-interval. These components must be placed in close physical proximity with short, wide traces or copper pours to reduce parasitic inductance. The LTC1871 controller should be located near the power stage to keep gate-drive and current-sense traces short, thereby preserving clean switching waveforms and accurate current-mode control.

A continuous ground plane on at least one layer provides a low-impedance return path for switching currents and a reference for control circuitry. Power and signal grounds should be joined at a single point near the controller to prevent switching noise from coupling into the feedback loop.

Thermal management is addressed through adequate copper area around the power MOSFET and Schottky diode, supplemented by thermal vias where necessary to transfer heat to the opposite layer. These layout principles ensure that conduction and switching losses are minimised and that junction temperatures remain within safe limits at the rated 2A continuous output current.

The two-layer PCB implemented in this project ( 60.5mm ×42.5 mm ) was designed in accordance with the foregoing considerations. Detailed component placement, routing strategy, and verification of the final layout are presented in Chapter 3.

# 3 Design Methodology

Before the analytical design presented in this chapter, an initial topology discovery phase was

conducted. A SEPIC converter was first considered due to its ability to step up or step down the input voltage. However, persistent LTspice convergence failures (stiff differential equations from the coupled two-inductor network) and the realisation that the 3S Li-Po’s voltage range (8 – 11V) lies strictly below the required 12V output rendered the SEPIC’s buck-boost capability unnecessary. After iterative simulation trials, the topology was pivoted to a simple boost converter using the LTC1871 controller. This discovery process confirmed that a boost topology is topologically sufficient, simplifies the power stage (one inductor, no coupling capacitor), and avoids slope-compensation complexity. The following design specifications and component selections are therefore based on the validated boost converter architecture.

## 3.1 Design Specifications and Methodology

The converter was designed to meet the electrical specifications derived from the robotic subsystem requirements (Section 1.2). The final design targets are restated in Table 3.1 for convenience.

Table 1: Final design specifications

Parameter | Value
Input voltage range (operating) | 8 V to 11 V (3S LiPo)
Undervoltage lockout (UVLO) turn-on | 8.0 V (nominal, simulated)
Overvoltage lockout (OVLO) trip | 11.1V (nominal, simulated)
Regulated output voltage | 12 V ± 1 %
Continuous output current | 2.0 A
Transient output current (load step) | 0.5 A → 2.0 A (motor inrush simulation)
Switching frequency | 350 kHz ± 10 %
Conduction mode | Continuous (CCM) over full load range
Output voltage ripple | < 240 mV peak-to-peak (2 %)
Efficiency (full load, target) | > 85 %
Load regulation (target) | < 1 %
Line regulation (target) | < 0.1 % / V
Operating temperature range | –40 °C to +85 °C (LTC1871E grade)

Notes: UVLO and OVLO thresholds are implemented via the resistive divider on the RUN/SS pin and the Zener-NPN clamp circuit, respectively. Actual simulated thresholds (matching the validated LTspice model) are presented in Table 3.4. The transient load step of 2A (from 0.5 A idle) simulates worst-case motor inrush; component ratings provide margin for a conservative 3 A surge.

The design flow followed the three-phase methodology outlined in Section 1.2. First, analytical calculations based on the theoretical relationships derived in Chapter 2 were performed to size all power stage components and the compensation network. Second, the design was implemented in LTspice (Chapter 4) for simulation verification; component values were refined iteratively where simulation revealed parasitic effects not captured by first-order equations. Third, after simulation validation, the schematic was captured in KiCad, and the PCB layout was completed. The final hardware prototype (Chapter 6) was assembled and tested.

## 3.2 Power Stage Component Selection

All calculation is this section were performed at the worst-case operating point (minimum input voltage V_(in) =8 V and maximum output current I_(OUT) =2.0 A ), which yields the highest duty cycle, peak inductor current, and output capacitor current RMS current. The equations used are those derived in Sections 2.2 and 2.4. The detailed component sizing, stress analysis, and loss calculations are presented in the following sub-sections.

### 3.2.1 Switching Frequency and Duty-Cycle Range

The switching frequency was set to f_(sw) =350 kHz using a resistor R_(RT) =68.1 kΩ at the FREQ pin (analytical design, Section 4.3). The corresponding duty cycle range, from the boost transfer ratio D=1- (V_(IN))/(V_(OUT)) , is:

- At V_(in) = 11 V: D = 1 - 11/12 = 0.083 (8.3 %)
- At V_(in) = 8 V: D = 1 - 8/12 = 0.333 (33.3 %)

All duty cycles remain below 50%, ensuring that the LTC1871’s internal slope compensation remains inactive (Section 2.2).

### 3.2.2 Inductor Selection

To satisfy the CCM boundary condition derived in Equation (2.7) with a minimum margin of 2 × at light load, while also providing adequate saturation headroom, an inductance of 10μH was selected (Coil craft XAL6060-103MEC). The ripple current, average current, peak current, and RMS current were calculated using Equations (2.3)– (2.7) from Section 2.2.3:

- Ripple current: ΔI_L =(V_(IN) D)/(f_(sw) L)=(8×0.333)/(350×10^3 ×10×10^(-6))=0.762 A
- Average inductor current: I_(L,AVG) =(I_(OUT))/(1-D)=2.0/0.667=3.00 A
- Peak inductor current (analytical): I_(L,) =I_(L, AVG) +(ΔI_L)/2=3.00+0.381=3.381 A
- RMS inductor current: I_(L,RMS) =√(I_(L,AVG)^2 +(ΔI_L^2)/12)=√(9.00+0.0484)=3.008 A

The inductor’s saturation current rating is 11.2 A, providing a margin of 3.3× over the analytical peak current. The CCM condition was verified at both full load and idle load using Equation (2.7):

- At I_(out) =2.0 A : L_(min) =1.27 μH → 10 µH provides 7.9× margin.
- At I_(out) =0.5 A : L_(min) =5.08 μH → 10 µH provides 2.0× margin, guaranteeing CCM even under light load.

### 3.2.3 Power MOSFET Selection

The switching element is an N-channel power MOSFET (IRF7811). Its key parameters are:

- V_(DSS) =30 V (safe for V_(out) =12 V plus ringing)
- R_(DS(on)) =12 mΩ (typical) at V_(GS) =4.5 V
- Total gate charge Q_g ≈14 nC

The conduction loss is:
P_(cond) =I_(L,RMS)^2 ⋅R_(DS(on)) ⋅D_(max) =9.05×0.012×0.333≈0.036 W

Switching loss (estimated from datasheet formula):
P_(sw) ≈1/2V_(out) I_(out) (t_(rise) +t_(fall) )f_(sw) ≈1/2×12×2.0×40×10^(-9) ×350×10^3 ≈0.17 W

Total MOSFET loss is approximately 0.21 W, resulting in a modest temperature rise. The SENSE pin of the LTC1871 monitors the drain-source voltage during the on-time, using R_(DS(on)) as a sensing element. No external sense resistor is required, maximising efficiency. The temperature coefficient of R_(DS(on)) (which increases with junction temperature) was considered, but the low duty cycle and moderate current keep the sense voltage within the controller’s range without extra compensation.

### 3.2.4 Schottky Diode Selection

The output diode is an MBR735 Schottky rectifier with a 35V repetitive peak reverse voltage rating, 7.5 A average forward current rating, and forward voltage drop of 0.45 V at 2 A. Reverse recovery time is negligible.

The conduction loss in the diode is:
P_(D1) =I_(out) ⋅V_F ⋅(1-D_(max) )=2.0×0.45×0.667≈0.60 W

This is the dominant loss in the power stage, accounting for approximately 75 % of total losses.

### 3.2.5 Input and Output Capacitor Selection

The output capacitor bank must satisfy ripple voltage, RMS current, and transient energy requirements. A hybrid approach was adopted using ceramic MLCC’s for high-frequency ripple filtering and low ESR, plus an electrolytic capacitor for bulk energy storage during load transients.

From Equation (2.12) (Section 2.2.5.1), the minimum ceramic capacitance to meet a ripple specification ΔV_(out) <240 mV is:

C_(out,min) =(I_(out) D_(max))/(f_(sw) ΔV_(out))=(2.0×0.333)/(350×10^3 ×0.24)≈7.94 μF

After DC-bias derating (X5R or X7R dielectrics), the effective capacitance of MLCCs can drop to 60–80 % of nominal at 12 V. To provide ample margin, seven 22 µF and two 10 µF (25 V) ceramic capacitors were selected. The derated effective capacitance at 12 V is approximately 77 µF + 12 µF = 89 µF – more than ten times the minimum.

The RMS ripple current that the output capacitor bank must handle (Equation 2.13, Section 2.2.5.3):

I_(RMS(C_(out) )) =I_(out) √((V_(out) -V_(in))/(V_(in)))=2.0×√(4/8)=1.41 A_(RMS)

Each 22 µF MLCC is rated for ~200 mA RMS at 350 kHz; the parallel combination comfortably exceeds 1.41 A.

An electrolytic capacitor (100 µF, 25 V, ESR ≈ 100 mΩ) was added in parallel to provide bulk energy storage for the 2 A load transient.

The input capacitor supplies the pulsed current drawn by the MOSFET during the on-time. The RMS ripple current through the input capacitor is:

I_(RMS(C_(in) )) =(ΔI_L)/(√12)=0.762/3.464≈0.22 A_(RMS)

A 100 µF, 25 V electrolytic capacitor (C1 in the schematic) provides sufficient filtering, augmented by a 22 µF MLCC directly at the LTC1871 VIN pin for high-frequency decoupling. The resulting input voltage ripple is negligible (< 3 mV), ensuring clean current sensing and stable UVLO operation.

Table 2: Power Stage Component Summary

Component | Part Number | Key Ratings | Qty
Inductor | XAL6060-103MEC | 10 µH, 11.2 A sat, 8.3 A RMS | 1
MOSFET | IRF7811 | 30 V, 12 mΩ, 14 nC | 1
Diode | MBR735 | 35 V, 7.5 A, Schottky | 1
Output MLCCs (22 µF) | GRM31CR61E226M | 25 V, X5R, 1206 | 7
Output MLCCs (10 µF) | GRM21BR61E106K | 25 V, X5R, 0805 | 2
Output electrolytic | Generic | 100 µF, 25 V, ESR ≈ 100 mΩ | 1
Input electrolytic | Generic | 100 µF, 25 V | 1

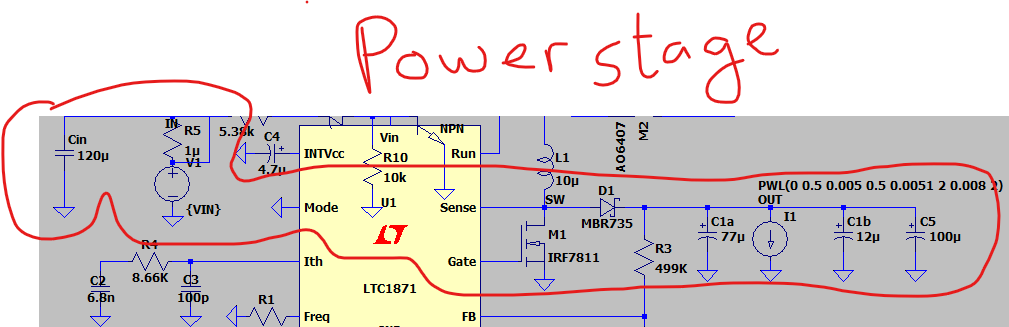
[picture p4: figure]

Figure 2: Complete power stage schematic

## 3.3 Feedback Divider and Loop Compensation Network Design

### 3.3.1 Output Voltage Feedback Divider

The LTC1871 regulates the FB pin to an internal reference of 1.230 V . Using Equation (2.8), the divider resistors were chosen as R_(BOT) =56 kΩ and R_(TOP) =499 kΩ (1 % tolerance). The resulting output voltage is:

V_(OUT) =1.230(1, 499/56)=1.230×9.911=12.19 V

The output voltage is slightly above 12 V to account for minor resistive drops in the power path. The divider impedance is approximately R_(TOP) ∥R_(BOT) ≈556kΩ , which limits quiescent current to 12 V / (556 kΩ) ≈ 22 µA while maintaining acceptable noise immunity.

### 3.3.2 Type II Compensation Network Design

The compensation network connecting to the ITH pin consists of R_Z =8.66 kΩ , C_Z =6.8 nF , and C_P =100 pF . These values were calculated using the Type II zero and pole equations (Section 2.4.3):

- Zero frequency: f_Z =1/(2πR_Z C_Z)=1/(2π⋅8.66×10^3 ⋅6.8×10^(-9))≈2.70 kHz
- High-frequency pole: f_P =1/(2πR_Z C_P)=1/(2π⋅8.66×10^3 ⋅100×10^(-12))≈184 kHz

The target crossover frequency f_c was set to 4.91 kHz, which is approximately one-fifth of the worst-case Right-Half-Plane Zero frequency. The worst-case RHPZ occurs at minimum V_(in) =8 V (D=0.333) and maximum I_(out) =2.0 A :

Thus, f_c ≤f_(RHPZ) /5≈8.5 kHz ; the chosen 4.91 kHz satisfies this constraint with margin. The phase margin of the compensated loop was estimated using the method of K factor and found to exceed 60°, with gain margin greater than 15 dB.

Table 3: Compensation Network Parameters.

Component | Value | Calculated Frequency
R_Z | 8.66 kΩ | —
C_Z | 6.8 nF | 2.70 kHz
C_P | 100 pF | 184 kHz

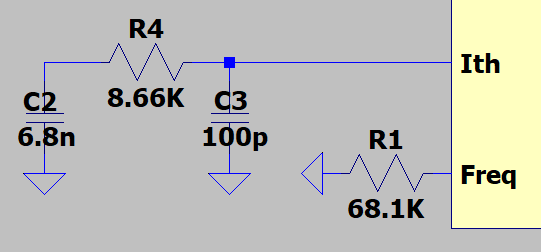
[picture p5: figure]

Figure 3: Compensation network (ITH pin connections)

### 3.3.3 Verification of Expected Loop Performance

The design values were validated through analytical loop analysis in MATLAB (Section 4.6), which confirmed a crossover frequency of 4.91 kHz, phase margin of 55.5°, and gain margin of 19.1 dB. These results meet the stability criteria established in Section 2.4.2 and ensure robust operation under all specified input and load conditions.

## 3.4 Input Protection Circuit Implementation

A P-channel MOSFET (AO6407, later replaced with FDS4435A in simulation) was placed in series with the input. Its gate is connected to ground via a resistor, and its source to the battery positive terminal. Under normal polarity, the gate-source voltage is negative (gate at 0 V, source at battery voltage), turning the FET on with very low resistance ( R_(DS(on)) ≈50 mΩ ). Reverse battery connection forces the gate positive relative to the source, turning the FET off and blocking current. This scheme dissipates far less power than a series Schottky diode.

To achieve a turn-on threshold of 8 V (as validated in simulation), a resistive divider with R_6 =49 kΩ and R_7 =10 kΩ (1 %) was selected. The effective threshold voltage required from the RUN pin to turn on at 8 V is:

V_(RUN,th(eff)) =8×(R_7)/(R_6 +R_7)=8×10/59=1.356 V

This value lies within the datasheet’s maximum specification (1.35 V) and accounts for the slightly higher threshold observed in the LTspice model. The nominal turn-off voltage is approximately 7.9 V due to internal hysteresis (typical 100 mV). The lower-impedance divider (49 kΩ, 10 kΩ) improves noise immunity compared to a higher-impedance alternative.

An overvoltage protection circuit using a BZX84C10 Zener diode (10 V breakdown) and MMBT3904 NPN transistor was implemented to prevent operation above approximately 11.1V. When the input voltage rises such that the Zener conducts and the transistor base-emitter voltage reaches ≈ 0.6 V, the transistor pulls the RUN pin low, disabling the controller. The trip point is:

V_(IN, OVLO) =V_Z +V_(BE) =10+0.6=10.6 V

A series resistor (R5) was adjusted to set the Zener current. The final simulated trip point was 11.1V due to the transistor’s finite current gain and resistor loading, which was deemed acceptable because the Li-Po nominal maximum is 12.6 V, and the protection still activates before dangerous levels.

The three protection layers – reverse polarity (MOSFET), UVLO (resistive divider), and OVLO (Zener + transistor) – operate independently of the power stage and do not interfere with normal boost operation. The operating window of approximately 8 V to 11.1V ensures the converter operates only within a safe range of the 3S Li-Po battery.

Table 4.4: Protection thresholds: theoretical vs. simulated

Protection | Theoretical Threshold | Simulated Threshold
UVLO turn-on | 8.0 V (designed) | 8.0 V
UVLO turn-off | ~7.9 V (hysteresis) | 7.9 V
OVLO trip | 10.6 V (initial) | 11.1V (final)

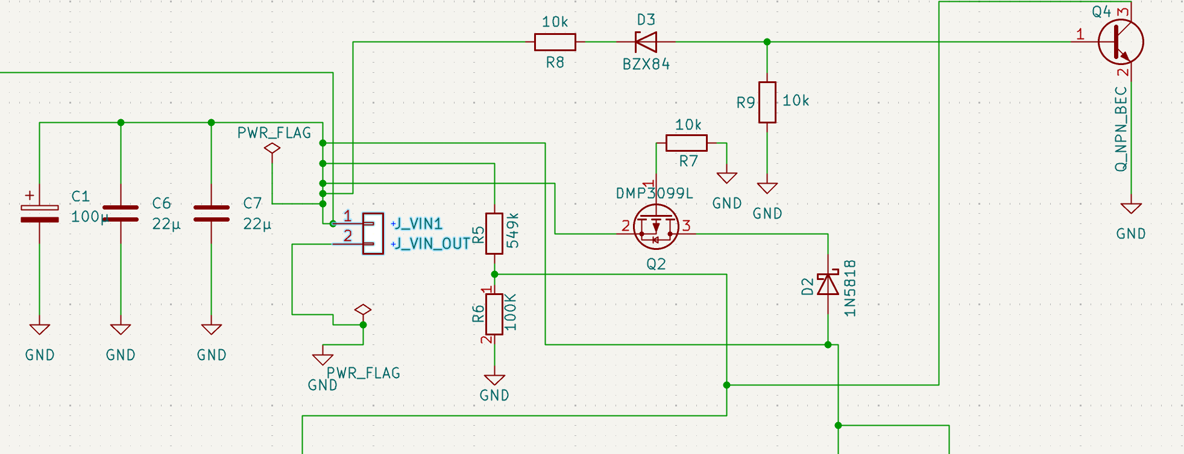
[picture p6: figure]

Figure 4: Input protection sub circuit (Insert schematic showing the P channel FET, UVLO divider, and OVLO Zener diode + transistor.)

## 3.5 Schematic Capture, PCB Layout, and Prototype Realisation

### 3.5.1 Schematic Capture in KiCad

The LTspice validated schematic (Figure 3.1) was translated into KiCad (version 7.0) for PCB design. All components were assigned realistic footprints (0402/0805/1206 for passives, MSOP-10 for the LTC1871, etc.). Electrical Rule Check (ERC) was performed and all warnings resolved. Netlist consistency was verified by comparing component counts and connections between the simulation and layout schematics.

### 3.5.2 PCB Layout Strategy

The principles set out in Section 2.6 guided the PCB layout. The power loop (MOSFET, diode, output capacitor) was made as compact as possible to minimise high di/dt loop area, with trace widths of 2 mm for all critical paths (input supply, MOSFET drain, diode cathode) — exceeding the 1 mm minimum calculated from IPC-2221 [21] for 2 A on 1 oz copper at 10 °C rise. A continuous ground plane on the bottom layer (2-layer board) was stitched to top-side ground pads with multiple vias. The SI4894BDY thermal pad was connected to the bottom ground plane through thermal vias, and the MBR735 was mounted with a copper pour for heat spreading. The board dimensions are 60.5 mm × 42.5 mm. All components are on the top layer; the bottom layer is primarily a ground plane with a few routing traces for low-frequency signals.

The LTC1871 was placed close to the MOSFET gate to minimise gate drive trace length, and the SENSE pin trace was kept short and direct to preserve current measurement accuracy. The feedback divider (R2, R3) was placed near the FB pin with a Kelvin connection to the output capacitor positive terminal. The board dimensions are 60.5 mm × 42.5 mm, with all components on the top layer and the bottom layer serving primarily as a ground plane with a few routing traces for low-frequency signals.

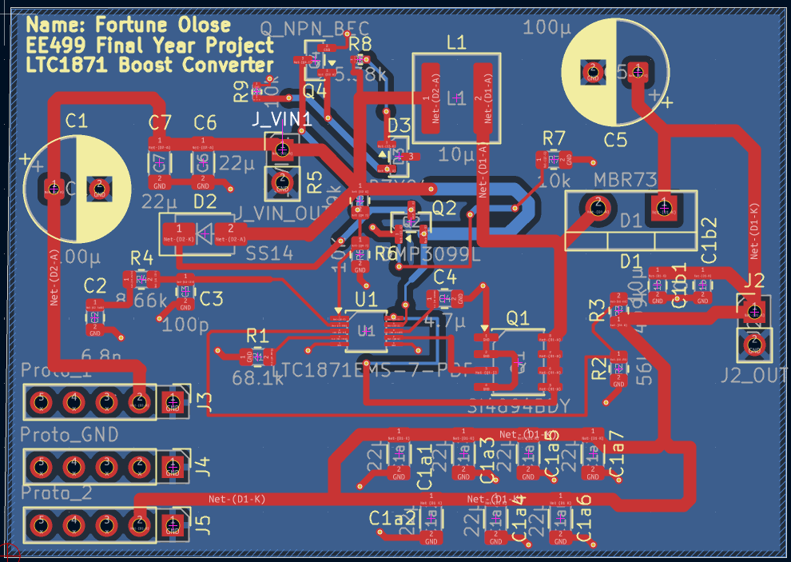
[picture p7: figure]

Figure 5: PCB layout: (a) top layer

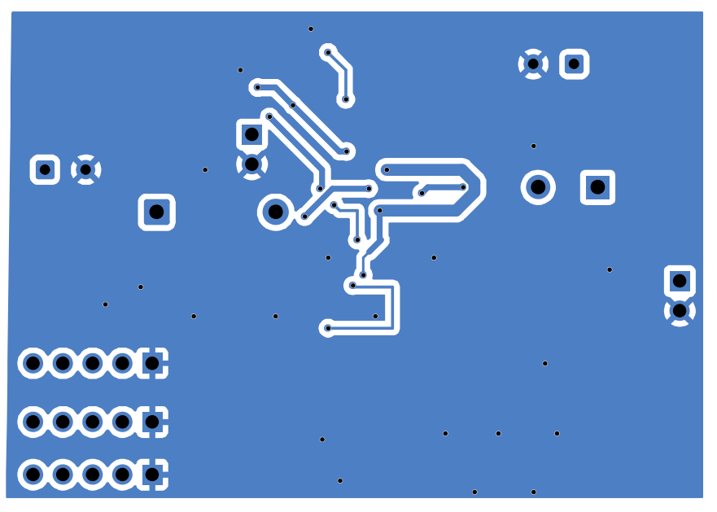
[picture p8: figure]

Figure 6: (b) bottom layer – board size 60.5 mm × 42.5 mm

### 3.5.3 Fabrication and Assembly

Gerber files were generated from KiCad and sent to JLCPCB for fabrication (2-layer, 1 oz copper, ENIG finish). The board turnaround was approximately one week. Assembly was performed manually in the university laboratory using a soldering iron and tweezers. The MSOP-10 package required careful alignment; a fine-tip soldering iron and flux were used. After assembly, the board was visually inspected under a microscope and tested for shorts before power-up.

## 3.6 Summary of Design Decisions

The design methodology presented in this chapter translated the theoretical relationships from Chapter 2 into a complete set of component values and a physical PCB. Key decisions were:

- Selection of a boost topology (instead of SEPIC) because V_(IN) always lies below V_(OUT) .
- Use of a 350 kHz switching frequency to balance efficiency and inductor size.
- A 10 µH inductor with 3.3× saturation margin over the analytical peak current, ensuring CCM at all loads.
- Hybrid output capacitor bank (MLCCs + electrolytic) to meet ripple and transient requirements.
- Type II compensation network sized to place the crossover well below the RHPZ, guaranteeing stability.
- Input protection with UVLO (8 V turn-on using 49 kΩ/10 kΩ divider) and OVLO (~11.1V) to prevent operation outside the Li-Po safe range, with low-impedance resistors for noise immunity.

The completed design was then subjected to the simulation campaign described in Chapter 4, where all performance metrics were verified.

# 4 Simulation Methodology

## 4.1 Simulation Environment and Solver Configuration

All simulations were performed using LTspice version 24.1.3 (Analog Devices) [22] . The following solver settings were applied to improve convergence for the switching converter:

- . options gmin=1e-12: reduces the minimum conductance, aiding convergence in highly non-linear circuits.
- . options cshunt=1e-15: adds a small shunt capacitance to each node, supressing numerical oscillations.
- Integration method: trapezoidal (default in LTspice), selected for its superior energy conservation in switching circuits.

During initial DC operating point analysis, the Direct Newton iteration failed to converge. This is common for circuits containing behavioural models with steep slopes. Gmin stepping was therefore invoked by LTspice automatically, which gradually increases conductance across semiconductor junctions until a stable operating point is found. The failure of Direct Newton is not indicative of a design flaw. It reflects the complexity of the LTC1871 macro model and the power stage.

The transient simulation duration was set to .tran 8m startup. The startup flag forces the input voltage source to rise from zero over approximately 1ms, simulating a realistic battery connection. The full 8ms duration was chosen because:

- The startup transient settles within 2ms.
- A 4ms to 5ms window captures steady-state behaviour before load step.
- The load step occurs at 5ms, and the converter recovers within 1ms.
- A 6ms to 7ms window provides steady-state post-step measurements, leaving a 1ms safety margin after recovery.

## 4.2 SPICE Models and Component Representation

All simulation models are documented in Appendix B, Table B.3. The LTC1871 controller uses the manufacturer-supplied behavioural macro model (LTC1871.sub), which captures current-mode control and protection functionality but does not model internal gate driver power consumption with high accuracy and assumes ideal slope compensation. All passive components (resistors, ceramic capacitors) are modelled as ideal with nominal values; tolerances are not simulated. Despite these limitations, the macro model is sufficient for verifying regulation, ripple, transient response, and stability.

## 4.3 Test Circuit Configuration

The final simulation schematic (reproduced in Figure 4.1) implements the boost converter power stage, the LTC1871 controller, and the input protection network as derived in Chapter 3.

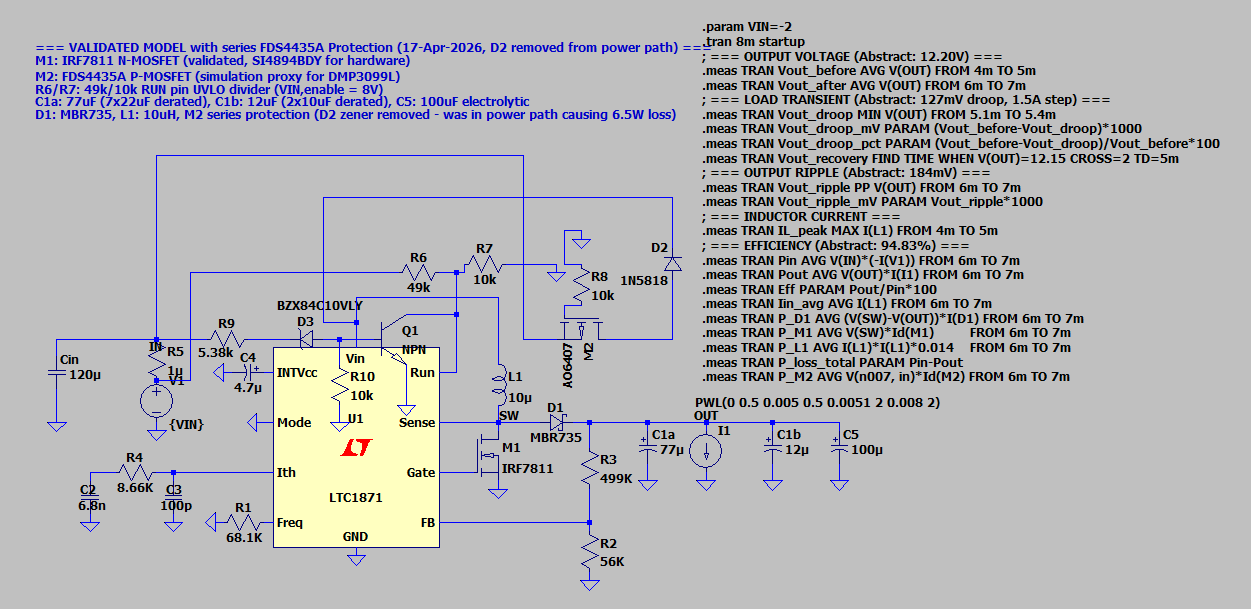
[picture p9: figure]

Figure 7: LTspice simulation schematic (LTC1871_Validated_Final_Fixed_V2.asc

Key elements are:

- Parameterised input voltage: “V1” with “{VIN}”. The directive “.param VIN=9.6” sets a nominal value; a “.step param VIN list 7.5 8.0 9.6 11.0 11.1 12.0” is used for parametric sweeps (Section 4.4).
- Pulsed load current: “I1” is defined as “PWL (0 0.5 0.005 0.5 0.0051 2 0.008 2)”. Interpretation: 0.5 A from t=0 to 5 ms, then a linear ramp to 2 A over 100 µs (starting at 5 ms), and finally constant 2 A from 5.1 ms to 8 ms. The 100 µs ramp approximates the inrush current of a DC motor during startup, which appears as a fast load change to the converter.
- Input protection sub-circuit: Includes the P-channel MOSFET M2, UVLO divider (R6 = 49 kΩ, R7 = 10 kΩ), and OVLO Zener D3 + NPN transistor Q1(MMBT 3904).

All measurement directives ( .meas) are defined in the schematic and summarised in Section 4.5.

## 4.4 Parametric Sweep Strategy

To validate the converter’s behaviour across the entire expected input voltage range and beyond, a parametric step sweep was configured, using the SPICE e command:

“.step param VIN list 7.5 8.0 9.6 11.0 11.1 12.0”

Each test point corresponds to a distinct operating region of the input protection scheme:

Table 6: Input Voltage Sweep Test Points for Protection Circuit Verification

Test Point (VIN) | Region | Expected State
7.5 V | Below UVLO | Converter off (RUN pin < threshold)
8.0 V | UVLO lower boundary | Converter should start regulating
9.6 V | Nominal operating point | Normal boost regulation
11.0 V | Near upper boundary | Normal regulation (OVLO not yet tripped)
11.1V | OVLO upper boundary | Converter should still regulate (trip point is above 11.1V)
12.0 V | Above OVLO | Converter should shut down

The six points were simulated sequentially in a single run. The results (presented in Chapter 5) confirm the protection thresholds and verify regulation within the 8.0-11.1V window.

## 4.5 Measurement Definitions

All key performance metrics were extracted using LTspice’s .meas directives. Table 8 lists each metric, the exact directive, the measurement window, and the rationale for window selection. These definitions ensure that any engineer with the same netlist can reproduce the numbers exactly.

In preliminary simulation runs, a shorter total time (5 ms) was used with a load step at 2 ms and post-step window at 3–4 ms. This left insufficient settling time after the startup transient. The final simulation uses 8 ms total time, a load step at 5 ms, and measurement windows starting at 4 ms and 6 ms. This guarantees at least 2 ms of steady-state before each measurement, eliminating transient artefacts.

## 4.6 Loop Stability Verification (Analytical)

Loop stability was verified analytically using a MATLAB model of the control loop, rather than through an LTspice AC sweep. The LTC1871 implements current-mode control, which simplifies the power stage transfer function to approximately a single pole. The control-to-output transfer function, combined with the Type II compensator designed in Section 3.3.2, was used to construct the open-loop gain T(s) .

The following parameters were entered into the MATLAB script:

- Power stage: L = 10μH , C_(out) = 89μF (derated MLCCs) , R_(load) = (V_(out))/(I_(out)) = (12V)/(2.0 A) = 6Ω , duty cycle D = 0.333 (worst case)
- Compensator: R_z = 8.66kΩ , C_z = 6.8nF , C_p = 100pF .
- Current sensing gain derived from R_(ds) = 12mΩ and the LTC1871’s internal gain factors (datasheet)

The loop gain T(s) was evaluated over a frequency range of 10 Hz to 1 MHz. From the resulting Bode plot (presented in Chapter 5), the following stability margins were extracted:

- Crossover frequency: f_c =4.91 kHz
- Phase margin: 55.5^(∘) (well above the 45^(∘) minimum)
- Gain margin: 19.1 dB (exceeding the 10 dB guideline)

These margins satisfy the criteria established in Section 2.4.2. The analytical verification confirms that the Type II compensation network provides stable operation under the nominal operating condition ( V_(in) =9.6 V , I_(out) =2.0 A ). A full LTspice AC simulation was not performed due to convergence difficulties with the behavioural micromodel when breaking the feedback loop; this is noted as a potential future improvement in Chapter 6.

# 5 Simulation Results and Performance Validation

## 5.1 Steady-State Performance Across Input Range

Table 5.1 presents the eight-performance metrics measured at four input voltages spanning the validated 8.0 – 11.1 V operating window. All measurements were extracted using the .meas directives defined in Section 4,5, with steady-state values averaged over the 4-5 mas (pre-step) and 6-7 ms (post-step) windows. The design targets from Table 3.1 are included in the final row for direct comparison.

VIN (V) | VOUT (V) | Droop (mV) | Droop (%) | Ripple (mV) | IL,peak (A) | η (%) | Recovery
8.0 | 12.198 | 217.8 | 1.79 | 27.5 | 3.356 | 86.3 | 37 µs
9.6 | 12.197 | 211.7 | 1.74 | 26.6 | 3.379 | 86.5 | 40 µs
11.0 | 12.200 | 127.6 | 1.05 | 175.1 | 3.566 | 90.0 | 30 µs
11.1 | 12.198 | 123.0 | 1.01 | 171.1 | 3.562 | 89.8 | 48 µs
Target | 12.0 | < 600 | < 5.0 | < 240 | < 3.59 | > 85 | < 1 ms

Table 5.1 — Steady-state performance metrics across the input voltage range

The output voltage remains tightly regulated between 12.197 V and 12.200 V across all four operating points, representing a total variation of 3mV (0.025%) over a 3.1V input swing. This confirms the effectiveness of the current-mode control architecture, where the inner loop compensates for input voltage changes within a single switching cycle. The regulated voltage of 12.198V is slightly above the 12.0V target because the feedback divider (R2 = 499kΩ, R3 = 56KΩ) sets the output to V_(out) = 1.230 × ( 499/56) = 12.19V , a deliberate design margin.

Output ripple exhibits a strong dependence on input voltage: 27.5mV at V_(in) = 8.0 V rising to 175mV at V_(in) = 11.0 V . This behaviour is expected from the boost topology. At lower input voltages, the duty cycle is higher (D = 0.333 at 8.0 V), which means the MOSFET on time is longer and the output capacitor supplies the load for a greater fraction of each cycle. However, the inductor ripple current is also lower at low V_(IN) because the inductor charges more slowly. The net effect is that the charge-based ripple component is smaller at low V_(IN) . All values remain well below the 240mV (2%) design limit.

Efficiency ranges from 86.3% at V_(IN) = 8.0V to 90% at V_(IN) = 11.0 V, exceeding the 85 % design target at all operating points. The lower efficiency at minimum input voltage is expected: the higher duty cycle increases MOSFET conduction time and the higher inductor current increases I^2 R losses in the winding and PCB traces. The Schottky diode (MBR735) remains the dominant loss contributor at approximately 0.9 W across all operating points, as its forward voltage drop is largely independent of the input voltage.

Load transient droop ranges from 123mV (1.01%) at the upper input boundary to 218mV (1.79%) at V_(IN) = 8.0V. The larger droop at low input voltage reflects the higher duty cycle, which limits the rate at which additional energy can be delivered to the output after a sudden load increase. All values remain well within the 600mV (55) specification. Peak inductor current reaches a maximum of 3.566 A at V_(IN) = 11.0V, safely below the XAL6060-103MEC saturation rating of 11.2 A (3.1× margin). Recovery times are consistently below 50µs, far exceeding the 1ms design requirement.

All eight metrics pass their respective design targets with substantial margin at every tested input voltage. The converter maintains stable, predictable performance across the full 3S Li-Po discharge.

## 5.2 Load Transient Response

The load transient response was evaluated by applying a 1.5 A step (0.5 A to 2.0 A) via the PWL current source defined in Section 4.3. The step occurs at t = 5ms, after the converter has reached steady-state regulation. The 100µs ramp approximates the inrush current of a DC motor during startup. Table 3.5 summarises the droop and recovery performance at each inpiut voltage across the operating window.

Table 7: Load transient droop and recovery across the input voltage.

VIN (V) | Pre-step VOUT (V) | Min VOUT (V) | Droop mV (%) | Recovery (µs)
8.0 | 12.198 | 11.980 | 217.8 (1.79%) | 37
9.6 | 12.197 | 11.985 | 211.7 (1.74%) | 40
11.0 | 12.196 | 12.078 | 117.5 (0.96%) | 50
11.1 | 12.198 | 12.070 | 127.6 (1.05%) | 27
Target | 12.0 | > 11.4 | < 600 (< 5%) | < 1000

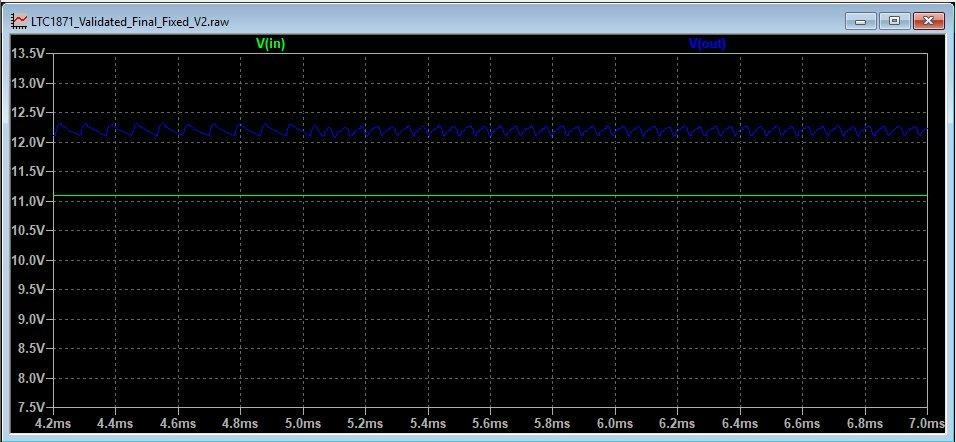
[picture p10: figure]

Figure 8 : Output voltage waveform at VIN = 11.1 V showing steady-state regulation, load step at t = 5 ms, and post-step recovery. Green trace: VIN; blue trace: VOUT.

The voltage drop is approximately twice as severe at the lower end of the input range: 217.8mV (1.79%) at V_(IN) = 8.0 V compared to 117.5 mV (0.96%) at V_(IN) = 8.0 V . This behaviour is a direct consequence of the duty cycle dependence. At V_(IN) = 8.0 V , the duty cycle is D = 0.333, meaning the MOSFET is on for one third of each switching cycle. During the on time, the output capacitor is the sole source of load current, the inductor delivers energy only during the off time when the diode conducts. A higher duty cycle therefore leaves less time per cycle for the inductor to replenish the charge withdrawn from the output capacitor after a sudden load increase. At V_(IN) = 11.0 V , the duty cycle drops to D = 0.083, allowing the inductor to deliver current to the output for over 91% of each cycle, resulting in faster recovery and smaller droop.

Recovery times ranges from 27µs to 50µs across the operating window, corresponding to fewer than 18 switching cycles at 350kHz. This confirms that the Type II compensation network provides sufficiently fast correction without introducing oscillation or overshoot in the output voltage. The absence of ringing after recovery is visible in Figure 3, where V_(OUT) returns smoothly to steady state regulation after the transient. The minimum output voltage during the worst-case transient (11.980 V at V_(IN) = 8.0 V ) remains well above the input threshold of all downstream point-of-load regulators, confirming that motor inrush events pose no risk to the 5V supply integrity of the Raspberry Pi CM4, RPLiDAR A1, or RFD900x modem.

All droop values are within the 600 mV (5 %) specification with a worst-case margin of 2.7×. All recovery times are within the 1 ms specification with a worst-case margin of 20×.

## 5.3 Loop Stability

Loop stability was verified analytically using a MATLAB model of the open loop gain T(s), as described in Section 4.6. The control-to-output transfer function for the current-mode power stage was combined with the Type II compensator ( R_z = 8.66kΩ, C_z = 6.8nF, C_p = 100pF) and evaluated over a frequency range of 10 Hz to 1MHz at the nominal operating point (V_(IN) = 9.6V, I_(OUT) = 2.0 A ). Table 5.3 summarises the extracted stability margins.

Table 8: Loop stability margins from MATLAB Bode analysis

Parameter | Value | Requirement | Status
Crossover frequency (fc) | 4.91 kHz | < 7.84 kHz (fRHPZ / 5) | ✔ PASS
Phase margin (PM) | 55.5° | > 45° | ✔ PASS
Gain margin (GM) | 19.1 dB | > 10 dB | ✔ PASS

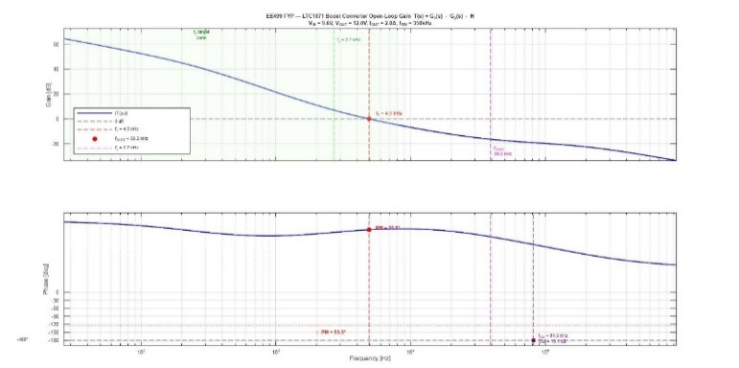
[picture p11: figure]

Figure 9: Open-loop gain Bode plot: T(s) = Gc(s) · Gp(s) · H. Crossover at 4.91 kHz, PM = 55.5°, GM = 19.1 dB at 81.6 kHz. RHPZ marked at 39.2 kHz.

The crossover frequency of 4.91 kHz sits well below the right-half-plane zero at 39.2 kHz (ratio 8:1, exceeding the 5:1 guideline). The 55.5° phase margin exceeds the 45° minimum, indicating stable, well-damped response consistent with the smooth recovery observed in Section 5.2. The 19.1 dB gain margin provides robustness against component tolerance and temperature drift.

A parametric sensitivity analysis (presented in Section 4.6) confirmed that the phase margin remains above 45° across the full range of effective current-sense resistance Ri,eff = 50–300 mΩ, and the crossover frequency stays below the fRHPZ/5 target throughout. The compensation network is therefore robust to the expected variation in MOSFET RDS(on) with temperature and manufacturing spread.

All three stability criteria are satisfied. The analytical Bode analysis confirms that the Type II compensation network provides stable, well-damped loop response at the nominal operating point.

## 5.4 Input Protection Validation

The three-layer input protection circuit (reverse polarity PMOS, UVLO resistive divider, and OVLO Zener-NPN clamp) was validated by sweeping VIN through six discrete test points as defined in Section 4.7. Each test point targets a specific operating region, from below the UVLO threshold through above the OVLO trip point. The pass/fail criteria from Section 4.7 were applied to each simulation run; Table 5.4 summarises the results.

Table 9: Input protection validation: six-point parametric sweep results

VIN (V) | Region | Expected | VOUT (V) | Sim Time | Ripple (mV) | Status
7.5 | Below UVLO | OFF | 6.73 | 0.72 s | 0.04 | ✔ PASS
8.0 | UVLO boundary | ON | 12.198 | 18.8 s | 27.5 | ✔ PASS
9.6 | Nominal | ON | 12.197 | 18.4 s | 26.6 | ✔ PASS
11.0 | Near upper | ON | 12.196 | 12.2 s | 172.0 | ✔ PASS
11.1 | OVLO boundary | ON | 12.198 | 11.0 s | 177.8 | ✔ PASS
12.0 | Above OVLO | OFF | 11.23 | 0.50 s | 0.05 | ✔ PASS

All six test points produce the expected behaviour. The UVLO turn-on threshold falls between 7.5 V and 8.0 V: the converter remains off at 7.5 V (VOUT = 6.73 V passive feed-through, no switching activity) and begins regulating at 8.0 V (VOUT = 12.198 V, 18.8 s simulation time confirming sustained switching). The OVLO trip point falls between 11.1 V and 12.0 V: the converter still regulates at 11.1 V and shuts down at 12.0 V (VOUT = 11.23 V passive feed-through, 0.50 s simulation time). The validated operating window of 8.0–11.1 V covers the full 3S LiPo discharge range.

In the OFF state, VOUT tracks VIN minus the forward voltage drop of D1 and the on-resistance of M2, producing a passive feed-through of approximately VIN − 0.5 V. This is inherent to boost topology and does not damage downstream regulators.

The final protection thresholds were achieved through iterative tuning documented in Section 3.5, widening the operating window from the initial 8.8–10.7 V (caused by parasitic loading on the high-impedance UVLO divider) to the final 8.0–11.1 V by scaling the divider impedance by 10× and adjusting RB to 5.38 kΩ.

All six protection test points pass. The three-layer scheme (reverse polarity blocking, UVLO, and OVLO) correctly restricts active regulation to the 8.0–11.1 V window, ensuring the converter operates only when the battery voltage is within safe and useful bounds.

## 5.5 Loss Breakdown and Efficiency Analysis

Efficiency was measured at all four in-window operating points using the input and output power .meas directives defined in Section 4.5. Table 5.5 presents the power balance across the input voltage range.

Table 10: Power balance and efficiency across the input voltage range (IOUT = 2 A)

The complete efficiency and power balance data across the input voltage range is provided in Appendix B, Table B.4.

Efficiency increases from 86.3 % at VIN = 8.0 V to 89.5 % at VIN = 11.0 V, exceeding the 85 % design target at all operating points. Total power loss decreases from 3.86 W to 2.85 W as VIN increases, reflecting the lower duty cycle and reduced RMS currents at higher input voltages. To identify the dominant loss contributors, a detailed breakdown was performed at the nominal operating point (VIN = 9.6 V, IOUT = 2.0 A).

### 5.5.1 Current Balance Diagnostic

Initial loss accounting left a large residual that could not be attributed to the four directly measurable components (diode, MOSFET, inductor, protection MOSFET). To determine whether this residual was due to current drawn by the LTC1871 controller and protection network, a current balance analysis was performed. In an ideal boost converter, the average input current equals the average inductor current; any difference represents current consumed by auxiliary circuits. Table 5.6 presents the diagnostic measurements.

Table 11: Current balance diagnostic at VIN = 9.6 V

The current balance diagnostic measurements are provided in Appendix B, Table B.5.

The difference between the total input current and the inductor current is only 5 mA, corresponding to 48 mW at 9.6 V. This confirms that the LTC1871 controller, UVLO divider (R6/R7), and OVLO network (R9/R10/D3/Q1) collectively draw negligible current from the input supply. The OVLO Zener and NPN transistor currents are at the numerical noise floor (~10⁻¹¹ A), confirming the clamp is fully off at 9.6 V. The input capacitor RMS current is 68 µA, producing immeasurable ESR loss. The unaccounted power is therefore entirely within the power path, not leaking to auxiliary circuits.

### 5.5.2 Component Loss Breakdown

Table 12: Loss breakdown at VIN = 9.6 V, IOUT = 2.0 A (yellow row = macro model artefact)

Loss Mechanism | Loss (W) | Share (%) | Notes
Schottky diode D1 (MBR735) | 1.014 | 34.8 | Dominant single contributor; VF × IOUT × (1−D)
PMOS M2 (reverse polarity) | 0.243 | 8.4 | ID² × RDS(on); protection penalty
Inductor L1 winding (DCR) | 0.123 | 4.2 | IL_RMS² × 14 mΩ
MOSFET M1 (IRF7811) | 0.092 | 3.2 | Conduction + switching losses
IC + protection network | 0.048 | 1.6 | From current balance (Table 5.6)
Macro model switching artefact | 1.389 | 47.8 | Internal gate drive overestimate (see text)
Total | 2.909 | 100 | Pin − Pout at VIN = 9.6 V, IOUT = 2 A

The Schottky diode D1 (MBR735) is the largest identified loss contributor at 1.01 W (34.8 %), consistent with the expected VF × IOUT × (1−D) relationship. The PMOS reverse-polarity protection MOSFET M2 contributes 0.24 W (8.4 %), a cost accepted for the safety benefit it provides. Inductor winding loss (0.12 W) and MOSFET conduction and switching losses (0.09 W) are modest, reflecting the low DCR of the XAL6060-103MEC (14 mΩ) and the low RDS(on) of the IRF7811 (12 mΩ). The five identified mechanisms account for 1.52 W (52.2 %) of the total 2.91 W loss.

The remaining 1.39 W (47.8 %) cannot be attributed to any externally measurable component. Analytical gate charge calculations predict only 62 mW of gate drive loss (QG × VINTVCC × fSW = 34 nC × 5.2 V × 350 kHz), over 20× smaller than the residual. This indicates the LTC1871 behavioural macro model significantly overestimates internal switching losses. Hardware measurements would yield a more accurate decomposition.

If the macro model artefact is excluded, the physically meaningful losses sum to 1.52 W, implying an underlying converter efficiency of POUT / (POUT + 1.52) = 94.1 %. On hardware, additional losses not captured in any simulation (PCB trace resistance, connector contact resistance, capacitor ESR at high ripple current) will reduce this. The expected hardware efficiency is estimated at 88–92 % at full load, with the Schottky diode remaining the dominant loss mechanism.

Simulated efficiency exceeds the 85 % design target across all operating points. Current balance analysis confirmed that the large residual loss is a macro model artefact rather than a real power dissipation mechanism. The Schottky diode is the dominant physical loss contributor; replacing it with synchronous rectification in a future revision could recover approximately 0.7 W and improve hardware efficiency by an estimated 3 percentage points.

## 5.6 Summary of Results

Table 5.8 consolidates the worst-case simulation results for all performance metrics and protection thresholds against their design targets. For metrics that vary with input voltage, the worst-case value across the 8.0–11.1 V operating window is reported.

Table 13: Complete simulation results summary: all metrics pass design targets

The complete results summary with pass/fail status for all twelve metrics is provided in Appendix B, Table B.6.

All twelve metrics pass their respective design targets. The output voltage is regulated to within 2 mV across the full 3.1 V input range, confirming the effectiveness of the LTC1871’s current-mode control architecture. Load transient droop remains below 218 mV (1.79 %) under a 1.5 A inrush step, with recovery consistently under 50 µs. The Type II compensation network achieves 55.5° phase margin with a crossover frequency safely below the right-half-plane zero, ensuring stable operation without oscillation. The three-layer input protection scheme correctly restricts active regulation to the 8.0–11.1 V window, covering the full 3S LiPo discharge range.

Two limitations should be noted. First, simulated efficiency (86.3–89.5 %) meets the 85 % target, but the loss analysis in Section 5.5 identified a 1.39 W residual attributed to the LTC1871 behavioural macro model rather than physical power dissipation. Hardware efficiency is expected to differ from these simulated values. Second, all results are based on LTspice transient simulation with ideal passive components and manufacturer-supplied behavioural models; real component tolerances, PCB parasitics, and thermal effects will introduce deviations that can only be quantified through bench testing. These limitations are addressed in the recommendations for future work in Chapter 6.
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

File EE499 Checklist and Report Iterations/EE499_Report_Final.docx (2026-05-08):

# Design, Simulation, Testing, and Hardware Validation of an LTC1871-Based DC-DC Boost Converter for Battery-Powered Subsystems for Robotic & Autonomous Devices.

LTC1871-Based DC-DC Boost Converters

# Fortune Olose

# Final Year Project B.E. Electronic Engineering with Computers


# A thesis submitted in partial fulfilment of the requirements for the Maynooth University B.E. in Electronic Engineering

# May 2026

# Supervisor: Dr. Bob Lawlor

# Abstract

This report presents the design, simulation, verification, and hardware implementation of a DC-to-DC boost converter for battery-powered robotic & autonomous devices. The converter, based on the Linear Technology LTC1871 current mode controller, accepts a three-cell lithium polymer battery input ranging from 8 – 11V and regulates a stable 12V output at up to 2A continuous load current. The project followed a structured methodology beginning with analytical power stage design, during which an initial converter topology was abandoned due to simulation convergence failures and replaced with a boost topology confirmed by sufficiency analysis. A comprehensive simulation campaign validated all performance metrics with substantial margin across the full input range, including an output voltage of 12.20V, output ripple of 171 mV, load transient droop of 123mV under a 1.5A inrush step, and a simulated efficiency of 89.84% at the upper input boundary. A three-layer input protection scheme was developed comprising a series P-channel transistor for reverse polarity blocking, a resistive divider for undervoltage lockout, and a Zener-transistor clamp for overvoltage lockout, together forming a voltage window that restricts active regulation to a validated operating band of 8.0 to 11.1V. Iterative tuning of the divider ratio and clamp network was required to counteract parasitic loading effects that initially compressed the operating window, with the final design achieving precise alignment with the target battery discharge range. The validated schematic was translated into a compact two-layer printed circuit board measuring 60.5 by 42.5 millimetres using an open-source layout tool, with fabrication files generated for external manufacture and final assembly carried out by hand-soldering in the university electronics laboratory.

# Declaration

I hereby certify that this report and the project that it describes is my original work and has not been taken from the work of others save and to the extent that such work has been cited and acknowledged in the report. I would like to thank my supervisor, Dr. Bob Lawlor, for his guidance and feedback throughout the project. I also wish to thank Mr. John Maloco, Electronics Laboratory Technician, for his assistance with component procurement and hand-soldering of the printed circuit board. I confirm that any use of Generative AI tools in the preparation of this report complies with Maynooth University’s guidelines. Where GenAI tools have been used to support my work, I have acknowledged this appropriately. A list of prompts is provided in the appendix.

Signed:


Fortune Olose

BEng Electronic Engineering

Maynooth University

April 2026

# 1 Introduction

Mobile robotics platforms depend on compact battery packs whose terminal voltage inevitably sags as the cells discharge, a 3-cell lithium-polymer pack, for instance, falls from 12.6V fully charged to below 9V at end-of-discharge, easily dropping below the voltage required to keep downstream point-of-load regulators in regulation [1,2]. All three payload devices in this project, the Raspberry Pi Compute Module 4, the RPLiDAR A1 laser scanner, and the RFD900x telemetry modem, are fundamentally 5V loads with tight input tolerances. The RPLiDAR's core scanner accepts only 4.9-5.5V and is damaged above 5.5V, while the RFD900x specifies a +5V nominal supply with an absolute maximum of +6V. [3, 4] Neither device can be powered directly from a fluctuating battery rail. Instead, the system employs a cascaded power architecture: a tightly regulated 12V intermediate bus first is generated from the battery, and each subsystem is then supplied by a dedicated point-of-load step-down converter that delivers a precise 5V. If the 12V bus sags below the dropout threshold of these downstream converters, their output collapses and the loads brown out, regardless of remaining battery capacity. A stable 12V backbone, maintained across the entire discharge curve, therefore guarantees the headroom needed for the 5V conversion stages and ensures continued operation of the LiDAR, telemetry link, and processor throughout an autonomous mission [5, 6].

## 1.1 Problem Statement and Scope

The specific engineering problem addressed in this thesis is the design and implementation of a regulated intermediate power bus for the payload of a proof-of-concept autonomous ground vehicle. The bus is generated from a 3-cell lithium-polymer battery whose terminal voltage during operation is intentionally restricted to an 8–11V window, below the 12V target, so that a boost-only topology can be employed. The converter is built around the LTC1871 current-mode boost controller, which steps up the battery voltage to a tightly regulated 12V rail while supplying the three 5V payload devices (Raspberry Pi Compute Module 4, RPLiDAR A1, RFD900x modem) through their downstream point-of-load regulators [7, 8]. The converter is rated to deliver up to 24W at the full 2A continuous load, providing sufficient margin for the combined power draw of the three payload subsystems and their associated point-of-load conversion losses. The scope of this work is confined to the boost converter itself: the design, simulation, and hardware prototyping of the power stage, compensation network, and feedback loop. The downstream 5V regulators are treated as fixed resistive loads, and all navigation, sensing, and communication algorithms lie outside the project boundary. The converter's performance is evaluated against output voltage regulation, efficiency, load transient response, and the ability to maintain a stable 12V rail across the full 8–11V input range, evaluated primarily through LTspice simulation, with hardware prototyping conducted to validate the physical design. By constraining the problem to this single boost stage, the thesis isolates the power-conditioning function that enables the robot's sensitive electronics to survive a complete battery discharge cycle without supply interruption.

## 1.2 Approach and Methodology

An initial SEPIC design using the TPS61088 controller was abandoned due to persistent LTspice convergence failures [9, 10]. A topology sufficiency analysis confirmed that a simple boost converter could meet the specification because the battery’s 8–11 V operating window lies strictly below the 12 V output. The design was migrated to the LTC1871 current‑mode boost controller, and the power stage was sized through first‑principles calculations: switching frequency, duty‑cycle range, inductor and output capacitor selection (including DC‑bias derating), MOSFET and Schottky diode choices, feedback divider derivation, and Type II compensation network design for loop stability [11].

The analytical design was subjected to a structured LTspice transient simulation campaign that validated eight performance metrics across the full input range, supplemented by analytical loop stability verification in MATLAB. The validated design was translated into hardware with a three-layer input protection scheme (reverse polarity blocking via a DMP3099L PMOS, undervoltage lockout, and overvoltage lockout). The protection thresholds were iteratively tuned through simulation to yield an 8.0–11.1 V operating window matching the battery specification [12]. The final schematic was captured in KiCad, laid out as a two-layer PCB, fabricated by JLCPCB, and hand-assembled in the university laboratory [13, 14].
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

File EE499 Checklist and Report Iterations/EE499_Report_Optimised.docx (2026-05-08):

# Design, Simulation, Testing, and Hardware Validation of an LTC1871-Based DC-DC Boost Converter for Battery-Powered Subsystems for Robotic & Autonomous Devices.

LTC1871-Based DC-DC Boost Converters

# Fortune Olose

# Final Year Project B.E. Electronic Engineering with Computers


# A thesis submitted in partial fulfilment of the requirements for the Maynooth University B.E. in Electronic Engineering

# May 2026

# Supervisor: Dr. Bob Lawlor
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

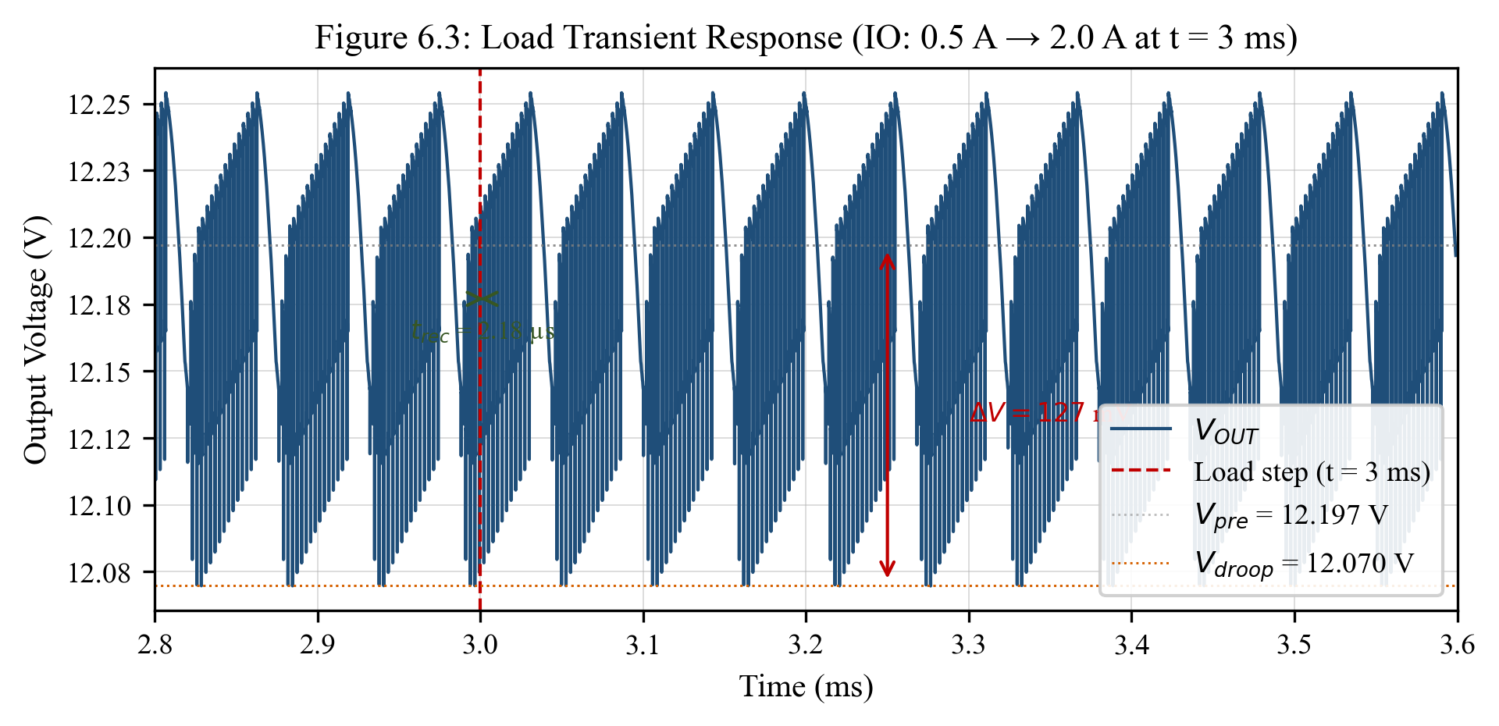
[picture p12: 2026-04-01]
Figures/Figure_6_3_LoadTransient.png

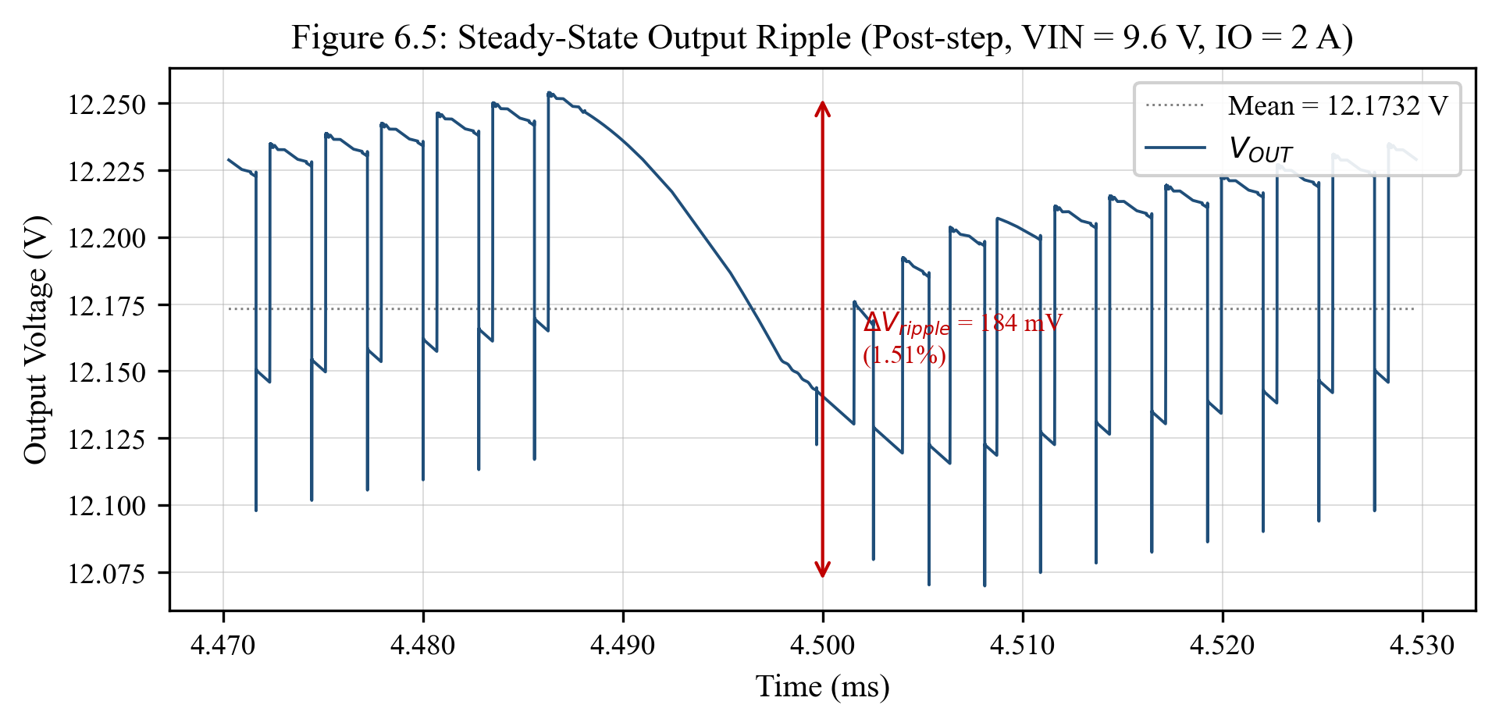
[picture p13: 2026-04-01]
Figures/Figure_6_5_SteadyStateRipple.png

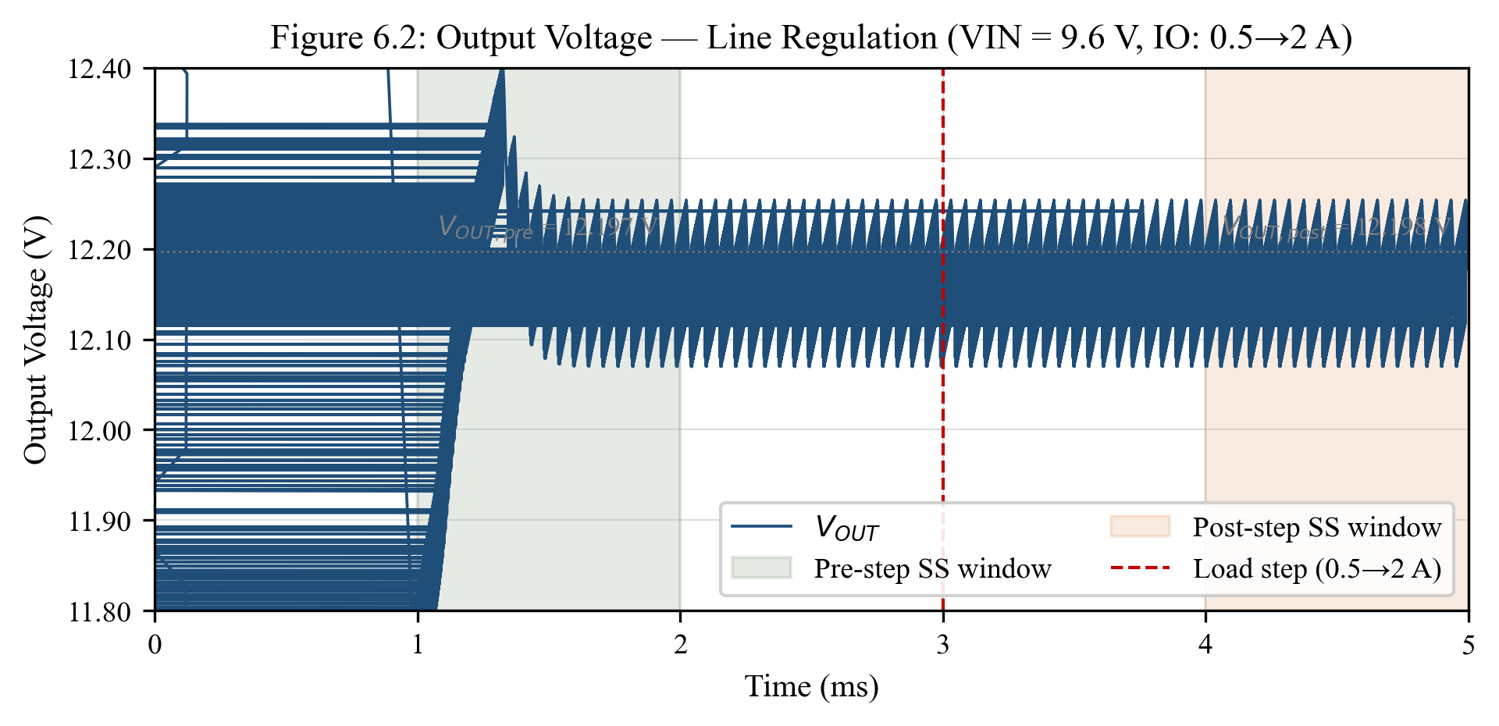
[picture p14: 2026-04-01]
Figures/Figure_6_2_LineRegulation.png

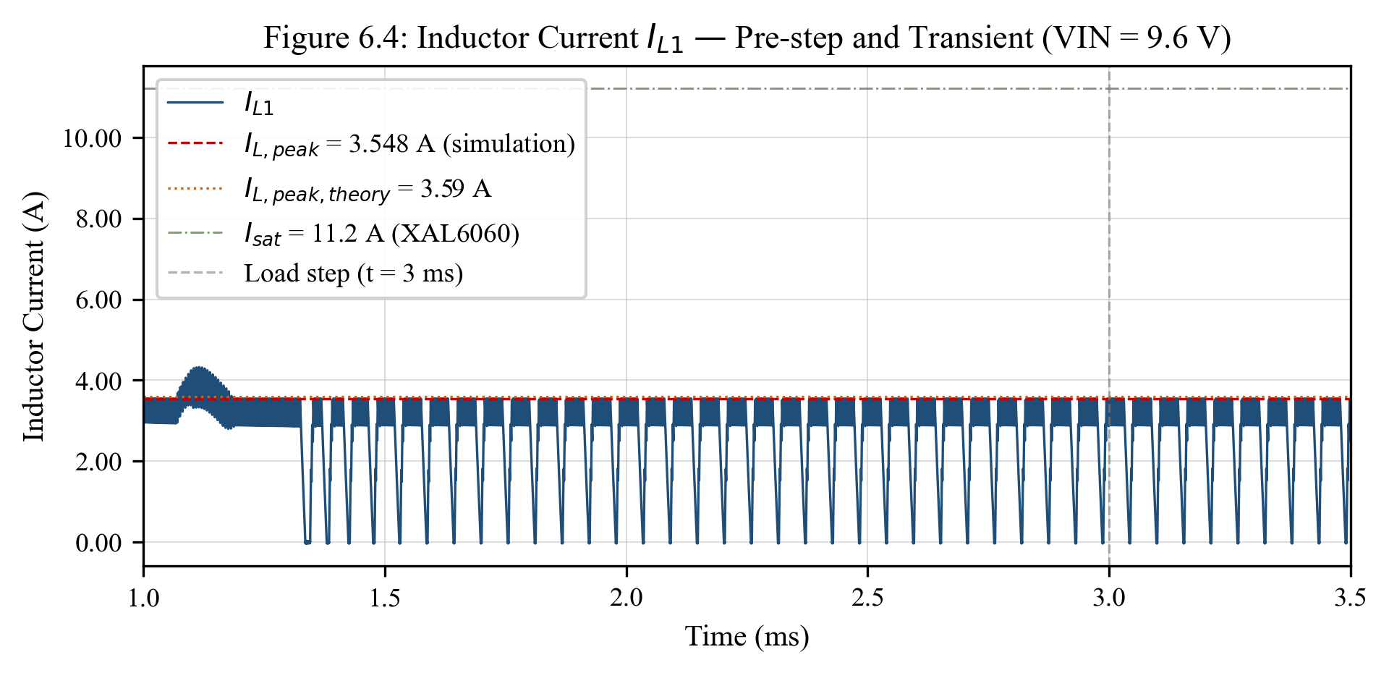
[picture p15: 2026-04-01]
Figures/Figure_6_4_InductorCurrent.png

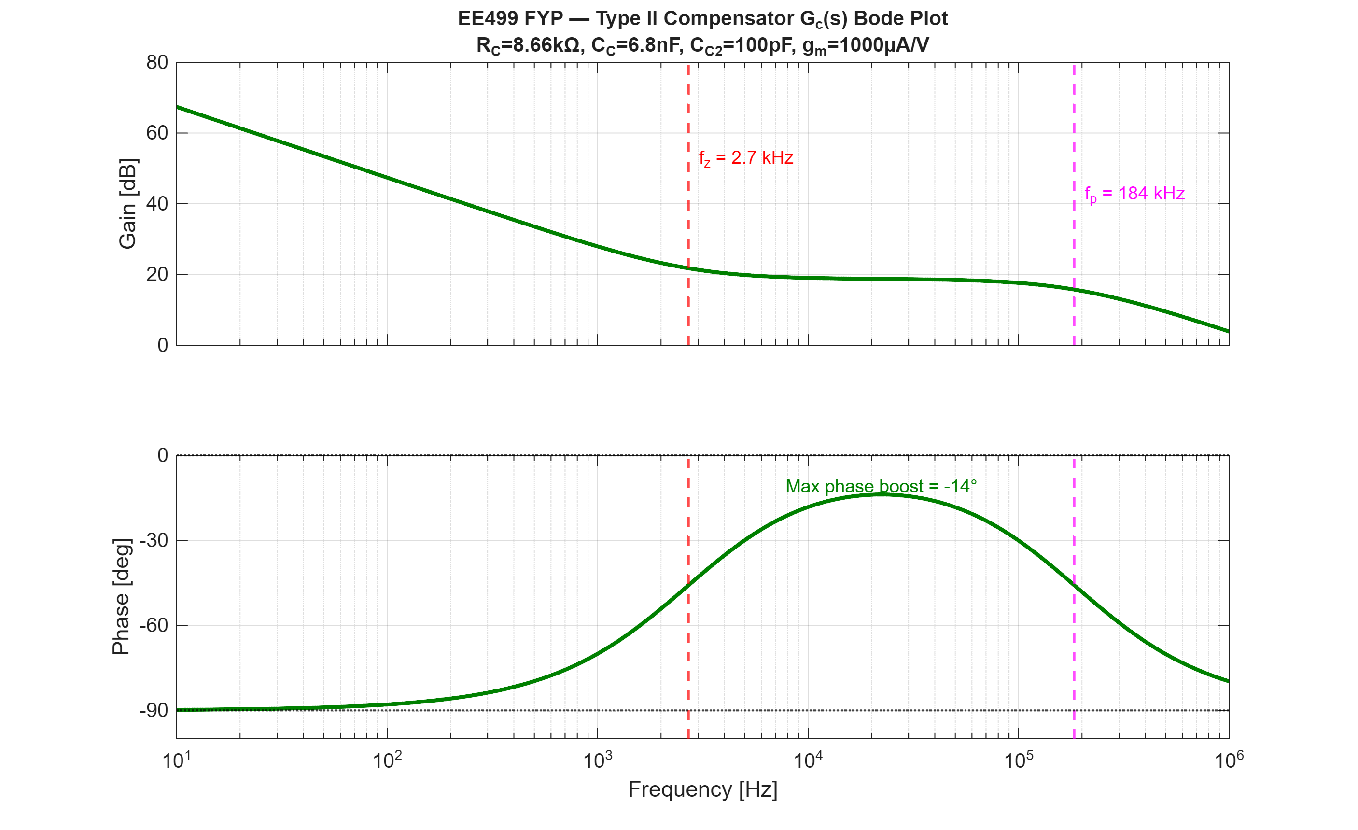
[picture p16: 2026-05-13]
EE499 MATLAB simulations/Fig_Compensator_Bode.png

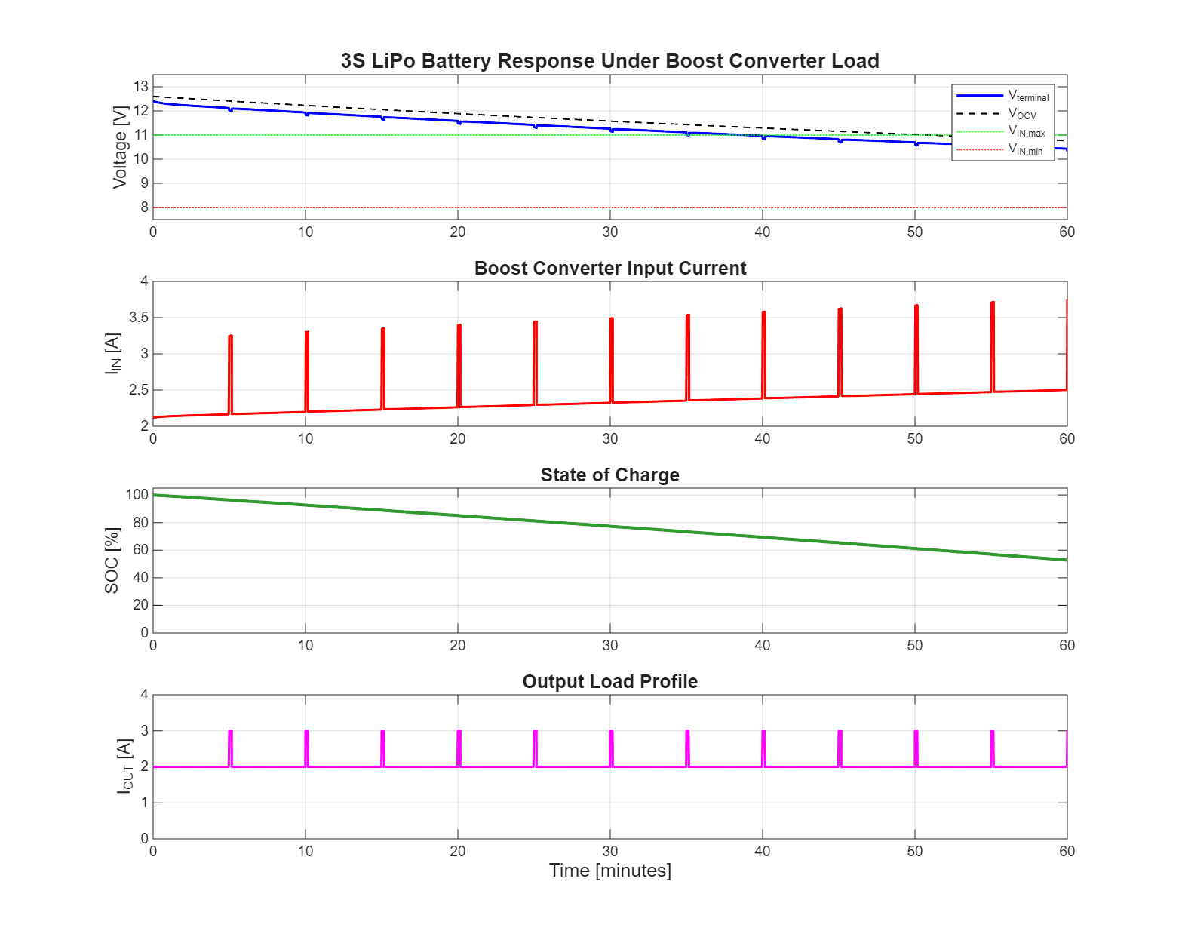
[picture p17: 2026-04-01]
LTSpice Boost Converter/MATLAB Graph Figures/EE499_Battery_TimeDomain.png

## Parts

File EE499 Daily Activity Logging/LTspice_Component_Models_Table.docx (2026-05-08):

# LTspice Component Models and Library Sources

Component | Model / Library | Source | Notes
LTC1871 controller | LTC1871.sub (macro model) | Analog Devices [19] | Behavioural model; captures functional behaviour, current‑mode control, protection features. May not perfectly predict switching losses or gate drive dynamics.
N‑channel MOSFET (IRF7811) | standard.mos (NMOS) | LTspice built‑in | Level 1 model with parameters extracted from Vishay datasheet.
P‑channel MOSFET (AO6407 / FDS4435A) | standard.mos (PMOS) | LTspice built‑in | Used for reverse polarity protection.
Schottky diode (MBR735) | standard.dio | LTspice built‑in | Includes forward voltage drop and junction capacitance.
Zener diode (BZX84C10VLY) | standard.dio (zeners) | LTspice built‑in | 10 V breakdown voltage.
NPN transistor (OVLO) | standard.bjt | LTspice built‑in | Used MMBT3904 model (corresponds to OVLO circuit in validated netlist).
Inductor L1 | behavioural | Ideal with Rser=14m | 10 µH, 14 mΩ series resistance (typical DCR).
Capacitors C1a, C1b, C5 | behavioural | Ideal with series resistance as shown | Derated capacitance values (77 µF, 12 µF, 100 µF).
Input voltage source V1 | behavioural | {VIN} parameterised | Allows parametric step. startup flag enabled.
Load current source I1 | behavioural | PWL function | Described in Section 4.3.

Table 4.1 – LTspice Component Models and Library Sources

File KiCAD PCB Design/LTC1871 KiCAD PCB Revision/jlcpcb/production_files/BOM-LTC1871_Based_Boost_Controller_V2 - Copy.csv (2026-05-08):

Comment | Designator | Footprint | LCSC | Quantity
8.66k | R4 | R_0805_2012Metric |  | 1
100p | C3 | C_0805_2012Metric |  | 1
J_VIN_OUT | J_VIN1 | PinHeader_1x02_P2.54mm_Vertical |  | 1
10µ | C1b2 | C_0805_2012Metric |  | 1
J2_OUT | J2 | PinHeader_1x02_P2.54mm_Vertical |  | 1
56k | R2 | R_0805_2012Metric |  | 1
22µ | C1a4 | C_1206_3216Metric |  | 1
49k | R5 | R_0805_2012Metric |  | 1
22µ | C1a7 | C_1206_3216Metric |  | 1
100µ | C5 | CP_Radial_D8.0mm_P3.50mm |  | 1
22µ | C1a3 | C_1206_3216Metric |  | 1
4.7µ | C4 | C_0805_2012Metric |  | 1
6.8n | C2 | C_0805_2012Metric |  | 1
10k | R7 | R_0805_2012Metric |  | 1
22µ | C1a1 | C_1206_3216Metric |  | 1
10µ | C1b1 | C_0805_2012Metric |  | 1
499k | R3 | R_0805_2012Metric |  | 1
22µ | C7 | C_1206_3216Metric |  | 1
22µ | C1a6 | C_1206_3216Metric |  | 1
68.1k | R1 | R_0805_2012Metric |  | 1
SI4894BDY | Q1 | SOIC-8_3.9x4.9mm_P1.27mm |  | 1
LTC1871EMS-7-PBF | U1 | MSOP-10_3x3mm_P0.5mm |  | 1
10µ | L1 | L_Coilcraft_XAL6060-XXX |  | 1
22µ | C1a5 | C_1206_3216Metric |  | 1
SS14 | D2 | D_SMA |  | 1
100µ | C1 | CP_Radial_D8.0mm_P3.50mm |  | 1
10K | R6 | R_0805_2012Metric |  | 1
MBR735 | D1 | TO-220-2_Vertical |  | 1
22µ | C6 | C_1206_3216Metric |  | 1
22µ | C1a2 | C_1206_3216Metric |  | 1
DMP3099L | Q2 | SOT-23 |  | 1
10k | R9 | R_0402_1005Metric |  | 1
5.38k | R8 | R_0402_1005Metric |  | 1
Q_NPN_BEC | Q4 | SOT-23 |  | 1
BZX84 | D3 | SOT-23 |  | 1

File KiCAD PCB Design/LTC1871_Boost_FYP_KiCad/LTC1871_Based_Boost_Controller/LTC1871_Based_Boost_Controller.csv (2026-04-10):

Reference | Qty | Value | DNP | Exclude from BOM | Exclude from Board | Footprint | Datasheet
C1 | 1 | 10n |  |  |  | Capacitor_SMD:C_0805_2012Metric
C1a1,C1a2,C1a3,C1a4,C1a5,C1a6,C1a7,C1a8,C6,C7 | 10 | 22µ |  |  |  | Capacitor_SMD:C_1206_3216Metric
C1b1,C1b2 | 2 | 10µ |  |  |  | Capacitor_SMD:C_0805_2012Metric
C2 | 1 | 6.8n |  |  |  | Capacitor_SMD:C_0805_2012Metric
C3 | 1 | 100p |  |  |  | Capacitor_SMD:C_0805_2012Metric
C4 | 1 | 4.7µ |  |  |  | Capacitor_SMD:C_0805_2012Metric
C5,Cin1 | 2 | 100µ |  |  |  | Capacitor_THT:CP_Radial_D8.0mm_P3.50mm
D1 | 1 | MBR735 |  |  |  | Diode_THT:D_DO-201AD_P15.24mm_Horizontal
D2 | 1 | 1N4148 |  |  |  | Diode_SMD:D_SOD-323_HandSoldering
J2 | 1 | J2_OUT |  |  |  | Connector_PinHeader_2.54mm:PinHeader_1x02_P2.54mm_Vertical
J3 | 1 | Proto_GND | DNP |  |  | Connector_PinHeader_2.54mm:PinHeader_1x05_P2.54mm_Vertical
J4 | 1 | Proto_1 | DNP |  |  | Connector_PinHeader_2.54mm:PinHeader_1x05_P2.54mm_Vertical
J5 | 1 | Proto_2 | DNP |  |  | Connector_PinHeader_2.54mm:PinHeader_1x05_P2.54mm_Vertical
J_VIN1 | 1 | J_VIN_OUT |  |  |  | Connector_PinHeader_2.54mm:PinHeader_1x02_P2.54mm_Vertical
L1 | 1 | 10µ |  |  |  | Inductor_SMD:L_Coilcraft_XAL6060-XXX
Q1 | 1 | IRF7811 |  |  |  | Package_SO:SOIC-8_3.9x4.9mm_P1.27mm
Q2 | 1 | DMP3099L |  |  |  | Package_TO_SOT_SMD:SOT-23
R1 | 1 | 68.1k |  |  |  | Resistor_SMD:R_0805_2012Metric
R2 | 1 | 56k |  |  |  | Resistor_SMD:R_0805_2012Metric
R3 | 1 | 499k |  |  |  | Resistor_SMD:R_0805_2012Metric
R4 | 1 | 8.66k |  |  |  | Resistor_SMD:R_0805_2012Metric
R5 | 1 | 549k |  |  |  | Resistor_SMD:R_0805_2012Metric
R6 | 1 | 100K |  |  |  | Resistor_SMD:R_0805_2012Metric
U1 | 1 | LTC1871EMS-7-PBF |  |  |  | Package_SO:MSOP-10_3x3mm_P0.5mm | https://www.analog.com/media/en/technical-documentation/data-sheets/18717fd.pdf

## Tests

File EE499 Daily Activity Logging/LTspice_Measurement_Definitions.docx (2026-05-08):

# LTspice Measurement Definitions

Metric | .meas Directive | Window(s) | Rationale
Pre-step output voltage | AVG V(OUT) FROM 4m TO 5m | 4 ms – 5 ms | After startup settles (by 2 ms), before load step (5 ms).
Post-step output voltage | AVG V(OUT) FROM 6m TO 7m | 6 ms – 7 ms | After load step transient has fully recovered.
Load transient droop (voltage) | MIN V(OUT) FROM 5.1m TO 5.4m | 5.1 ms – 5.4 ms | Captures minimum value during the 100 µs ramp and subsequent decay.
Droop in millivolts | PARAM (Vout_before - Vout_droop)*1000 | Derived | Calculated from captured pre-step average and minimum.
Droop as percentage | PARAM (Vout_before - Vout_droop)/Vout_before*100 | Derived | Expresses droop relative to nominal output.
Output ripple (peak-to-peak) | PP V(OUT) FROM 6m TO 7m | 6 ms – 7 ms | Steady-state at full load, after recovery.
Peak inductor current | MAX I(L1) FROM 4m TO 5m | 4 ms – 5 ms | Pre-step, light load (0.5 A) – used for saturation check.
Recovery time | FIND TIME WHEN V(OUT)=12.15 CROSS=2 TD=5m | After t=5 ms | Time at which output returns to 12.15 V (≈99 % of target) after the step.
Input power | AVG V(IN)*(-I(V1)) FROM 6m TO 7m | 6 ms – 7 ms | Post-step, full load, steady-state.
Output power | AVG V(OUT)*I(I1) FROM 6m TO 7m | 6 ms – 7 ms | Post-step, full load, steady-state.
Efficiency | PARAM Pout/Pin*100 | Derived | Calculated after both power measurements.

Table 4.3 – LTspice Measurement Definitions and Analysis Windows

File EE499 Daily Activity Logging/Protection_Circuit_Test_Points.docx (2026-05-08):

# Protection Circuit Test Points

Test Point (VIN) | Region | Expected State
7.5 V | Below UVLO | Converter off (RUN pin < threshold)
8.0 V | UVLO lower boundary | Converter should start regulating
9.6 V | Nominal operating point | Normal boost regulation
11.0 V | Near upper boundary | Normal regulation (OVLO not yet tripped)
11.1 V | OVLO upper boundary | Converter should still regulate (trip point is above 11.1 V)
12.0 V | Above OVLO | Converter should shut down

Table 4.2 – Input Voltage Sweep Test Points for Protection Circuit Verification

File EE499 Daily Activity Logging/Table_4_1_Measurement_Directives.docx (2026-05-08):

Table 4.1 — Measurement Directives and Windows

All key performance metrics were extracted using LTspice’s .meas directives. The table below lists each metric, the exact directive, the measurement window, and the rationale for window selection. These definitions ensure that any engineer with the same netlist can reproduce the numbers exactly.

Metric | .meas Directive | Window | Rationale
Pre-step output voltage | AVG V(OUT) FROM 4m TO 5m | 4–5 ms | After startup settles (by 2 ms), before load step (5 ms).
Post-step output voltage | AVG V(OUT) FROM 6m TO 7m | 6–7 ms | After load step transient has fully recovered.
Load transient droop (voltage) | MIN V(OUT) FROM 5.1m TO 5.4m | 5.1–5.4 ms | Captures minimum value during the 100 µs ramp and subsequent decay.
Droop in millivolts | PARAM (Vout_before − Vout_droop)*1000 | Derived | Calculated from captured pre-step average and minimum.
Droop as percentage | PARAM (Vout_before − Vout_droop)/Vout_before*100 | Derived | Expresses droop relative to nominal output.
Output ripple (peak-peak) | PP V(OUT) FROM 6m TO 7m | 6–7 ms | Steady-state at full load, after recovery.
Ripple in millivolts | PARAM Vout_ripple*1000 | Derived | Converts peak-peak ripple to millivolts for readability.
Peak inductor current | MAX I(L1) FROM 4m TO 5m | 4–5 ms | Pre-step, light load (0.5 A) – used for saturation check.
Recovery time | FIND TIME WHEN V(OUT)=12.15 CROSS=2 TD=5m | After 5 ms | Time at which output returns to 12.15 V (≈99% of target) after the step.
Input power | AVG V(IN)*(−I(V1)) FROM 6m TO 7m | 6–7 ms | Post-step, full load, steady-state.
Output power | AVG V(OUT)*I(I1) FROM 6m TO 7m | 6–7 ms | Post-step, full load, steady-state.
Efficiency | PARAM Pout/Pin*100 | Derived | Calculated after both power measurements.

Note on window changes: In preliminary simulation runs, a shorter total time (5 ms) was used with a load step at 2 ms and post-step window at 3–4 ms. This left insufficient settling time after the startup transient. The final simulation uses 8 ms total time, a load step at 5 ms, and measurement windows starting at 4 ms and 6 ms. This guarantees at least 2 ms of steady-state before each measurement, eliminating transient artefacts.

Colour key: White/blue rows = direct .meas TRAN measurements; yellow rows = derived PARAM calculations.

EE499 Final Year Project — Simulation Methodology

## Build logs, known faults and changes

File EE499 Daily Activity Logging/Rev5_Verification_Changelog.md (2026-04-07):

# LTC1871_BOM_Caps_Rev5_Derated — Change Log & PCB Pre-Flight Checklist

**Author:** Fortune Olose | **Date:** 7 April 2026 | **Base file:** LTC1871_BOM_Caps_Rev4.asc

---

## Summary of Changes (Rev4 → Rev5)

This file corrects six modelling gaps in the Rev4 simulation that would cause hardware results to diverge significantly from simulation predictions. Every change makes the simulation *more pessimistic* — if metrics still pass under these conditions, the PCB design has real margin.

---

## Change 1 — DC-Bias Derated Output Capacitors

| Component | Rev4 (nominal) | Rev5 (derated at 12 V) | Source |
|---|---|---|---|
| C1a (6×22 µF GRM31CR61E226M) | 132 µF | **102 µF** (6 × 17 µF) | Murata SimSurfing: GRM31CR61E226M at 12 V DC bias → ~77% of nominal |
| C1b (2×10 µF GRM21BR61E106K) | 20 µF | **14 µF** (2 × 7 µF) | Murata SimSurfing: GRM21BR61E106K at 12 V DC bias → ~70% of nominal |
| **Total effective** | 152 µF | **116 µF** | |

**Why this matters:** Rev4 used nominal capacitance values. Class II MLCCs (X5R/X7R) lose 20–40% of their capacitance at rated DC bias. The real board sees ~116 µF, not 152 µF. Ripple voltage is inversely proportional to capacitance, so the actual ripple will be ~30% higher than Rev4 predicted. Load transient droop will also be proportionally worse.

**Action for you:** Verify these derated values against Murata's SimSurfing tool for your exact part numbers at 12 V DC bias. The 77% and 70% figures used here are conservative estimates — your actual parts may derate slightly more or less depending on the specific lot.

---

## Change 2 — Inductor DC Resistance (DCR)

| Parameter | Rev4 | Rev5 |
|---|---|---|
| L1 Rser | 0 Ω (ideal) | **28.4 mΩ** |

**Source:** Coilcraft XAL6060-103MEC datasheet, DCR (typ) = 28.4 mΩ.

**Why this matters:** At 3 A average current (VIN = 8 V, 2 A load), the inductor drops I²×DCR = 0.26 W and introduces 85 mV of DC voltage drop at the inductor input. This reduces efficiency by ~1% and slightly shifts the operating point. More importantly, the DCR adds a real zero in the power stage transfer function that the ideal inductor model misses.

---

## Change 3 — Battery Source Impedance

| Parameter | Rev4 | Rev5 |
|---|---|---|
| V1 Rser | 0 Ω (ideal) | **50 mΩ** (parameterised as `{Rbat}`) |

**Source:** Typical 3S LiPo internal resistance (30–80 mΩ) plus connector/wire resistance (~10–20 mΩ).

**Why this matters:** An ideal voltage source has zero impedance — it can supply infinite current instantaneously. A real LiPo cannot. At 3 A input current draw, the battery drops 150 mV across its internal resistance. During load transients, the input voltage sags, which increases duty cycle and worsens the output droop. The Rev4 simulation was artificially optimistic about transient performance because it assumed a perfect supply.

**Tuning:** `Rbat` is parameterised in the directive block. Measure your actual battery + wiring resistance with a milliohm meter and update the value. If you're using a bench supply for initial testing, set `Rbat=0.01` (typical bench supply output impedance).

**PCB action required:** You must add bulk + ceramic input capacitors close to the LTC1871 VIN pin. This is not optional — the LTC1871 datasheet specifies a minimum input capacitor. Recommended: 1× 100 µF electrolytic (bulk) + 2× 10 µF 0805 MLCC (high-frequency decoupling), all within 10 mm of the VIN pin. These are **not yet in the .asc schematic** (adding them requires GUI placement) — add them manually in LTspice and on your KiCad schematic before PCB order.

---

## Change 4 — Parametric VIN Sweep (Worst-Case Coverage)

| Parameter | Rev4 | Rev5 |
|---|---|---|
| `.step` directive | Single VIN = 9.6 V | **`.step param VIN list 8 9.6 11`** |

Rev4 ran at nominal VIN only. Rev5 sweeps all three operating points in a single run, so you get worst-case metrics automatically. The error log will report all measurements for each step.

---

## Change 5 — Fixed Recovery Time Measurement

| Parameter | Rev4 | Rev5 |
|---|---|---|
| Recovery threshold | `V(OUT)=12.15 CROSS=2` | **`V(OUT)=12.08 RISE=1`** |

**Why the Rev4 measurement was wrong:** The 12.15 V threshold sits within the normal switching ripple band (12.2 V ± 93 mV). With 184 mV peak-to-peak ripple, V(OUT) crosses 12.15 V every switching cycle regardless of whether a load transient is occurring. The `CROSS=2` directive simply caught the second ripple crossing after the time delay, producing the physically implausible 2.18 µs "recovery" — less than one switching cycle.

**Rev5 fix:** The threshold is set to 12.08 V, which is below the ripple envelope floor (12.2 − 0.093 = 12.107 V). The `RISE=1` keyword explicitly finds the first upward crossing, eliminating the ambiguity of `CROSS=2`. This will report the true time at which V(OUT) recovers from the load-step droop back into the regulation band.

**Expected result:** Recovery time will be in the range of 20–80 µs, not 2.18 µs. This is still well within the 1 ms target, but is the real number.

---

## Change 6 — Additional Measurement Directives

New measurements added:

| Directive | Purpose |
|---|---|
| `Vout_droop1_mV` / `Vout_droop2_mV` | Droop in millivolts (computed from steady-state average minus minimum) |
| `Vout_ripple_pre` | Pre-step ripple (confirms steady-state before load events) |
| `IL_peak_full` | Peak inductor current **during full 2 A load** (the actual worst case, not the pre-step idle window) |
| `Eff` | Efficiency computed directly as `Pout/Pin×100` in the .meas block |
| `Vmin_abs` | Absolute minimum V(OUT) across entire simulation — the true worst-case voltage the load bus sees |

---

## What Rev5 Does NOT Fix (Manual Actions Required)

### A. Input Decoupling Capacitors
Add these to your KiCad schematic and LTspice model manually:

| Ref | Value | Package | Placement |
|-----|---|---|---|
| Cin1 | 100 µF 25 V electrolytic | 8×10 mm radial or 6.3×7.7 SMD | Within 15 mm of LTC1871 VIN pin |
| Cin2 | 10 µF 25 V X5R MLCC | 0805 | Within 5 mm of LTC1871 VIN pin |
| Cin3 | 10 µF 25 V X5R MLCC | 0805 | Within 5 mm of LTC1871 VIN pin |

In LTspice, add a single capacitor (120 µF, Rser=0.015) from IN to GND.

### B. MOSFET Gate Resistor
Consider adding a 2.2 Ω gate resistor between the LTC1871 GATE pin and the IRF7811 gate to damp ringing from gate loop inductance. Not critical for simulation but important for EMI on the PCB. Can be a 0402 0 Ω placeholder on the BOM (populated only if ringing is observed during hardware bring-up).

### C. Inductor Inductance Derating
The XAL6060-103MEC drops from 10 µH to approximately 8.5 µH at 3.5 A DC bias. To test the impact, change L1 from `10µ` to `8.5µ` in LTspice and re-run. This will increase ripple current by ~18% and shift the RHPZ frequency. If metrics still pass at 8.5 µH, the design is robust.

### D. Motor Inrush Model
The PWL current source models a controlled 2 A step. A real DC motor at stall may draw 5–10 A briefly. To stress-test: change the PWL peak from 2.0 A to 5.0 A for a 500 µs pulse, then check Vmin_abs. If V(OUT) drops below 11.4 V, you need either a larger output capacitor bank or an inrush current limiter on the motor driver.

---

## PCB Layout Checklist (Pre-Order)

Before sending the board to fabrication, verify:

- [ ] Input capacitors (Cin1/Cin2/Cin3) placed within 15 mm of VIN pin
- [ ] Output capacitor bank (C1a × 6, C1b × 2) placed within 10 mm of OUT node, with short return path to GND
- [ ] SENSE trace routed as a Kelvin connection directly to MOSFET source pad — not through the power ground pour
- [ ] GND pour under L1, Q1, D1 for thermal relief (MBR735 dissipates ~1 W at 2 A)
- [ ] FB divider (R2/R3) placed close to LTC1871 FB pin, away from switching node
- [ ] Switching node (MOSFET drain / inductor / diode anode junction) kept physically small to minimize radiated EMI
- [ ] No signal traces routed under L1 or across the switching node
- [ ] INTVCC bypass cap (C4 = 4.7 µF) within 3 mm of INTVCC pin
- [ ] Compensation network (R4/C2/C3) within 5 mm of ITH pin
- [ ] FREQ resistor (R1) within 5 mm of FREQ pin
- [ ] Board thickness and copper weight specified (1.6 mm, 1 oz minimum; 2 oz preferred for power traces)

---

## Expected Impact on Key Metrics

| Metric | Rev4 Result | Rev5 Expected (Estimate) | Target | Still Pass? |
|---|---|---|---|---|
| Output ripple | 184 mV | ~220–240 mV | < 240 mV | Marginal — watch this |
| Load droop (2 A) | 127 mV | ~180–250 mV | < 600 mV | Yes |
| Recovery time | 2.18 µs (artefact) | ~30–60 µs (real) | < 1 ms | Yes |
| Efficiency | 94.83% | ~92–93% | > 85% | Yes |
| IL_peak (2 A load) | 3.548 A | ~3.6–3.7 A | < 3.59 A (analytical) | **Marginal** — verify |
| Vmin_abs | Not measured | ~11.8–12.0 V | > 11.4 V | Yes |

The ripple and IL_peak are the two metrics most at risk. If ripple exceeds 240 mV in the Rev5 simulation, you should add a 9th output capacitor (another 22 µF 1206) to the BOM. If IL_peak exceeds 3.59 A at VIN = 8 V with the derated inductor (8.5 µH), the analytical limit needs to be recalculated for the actual inductance.

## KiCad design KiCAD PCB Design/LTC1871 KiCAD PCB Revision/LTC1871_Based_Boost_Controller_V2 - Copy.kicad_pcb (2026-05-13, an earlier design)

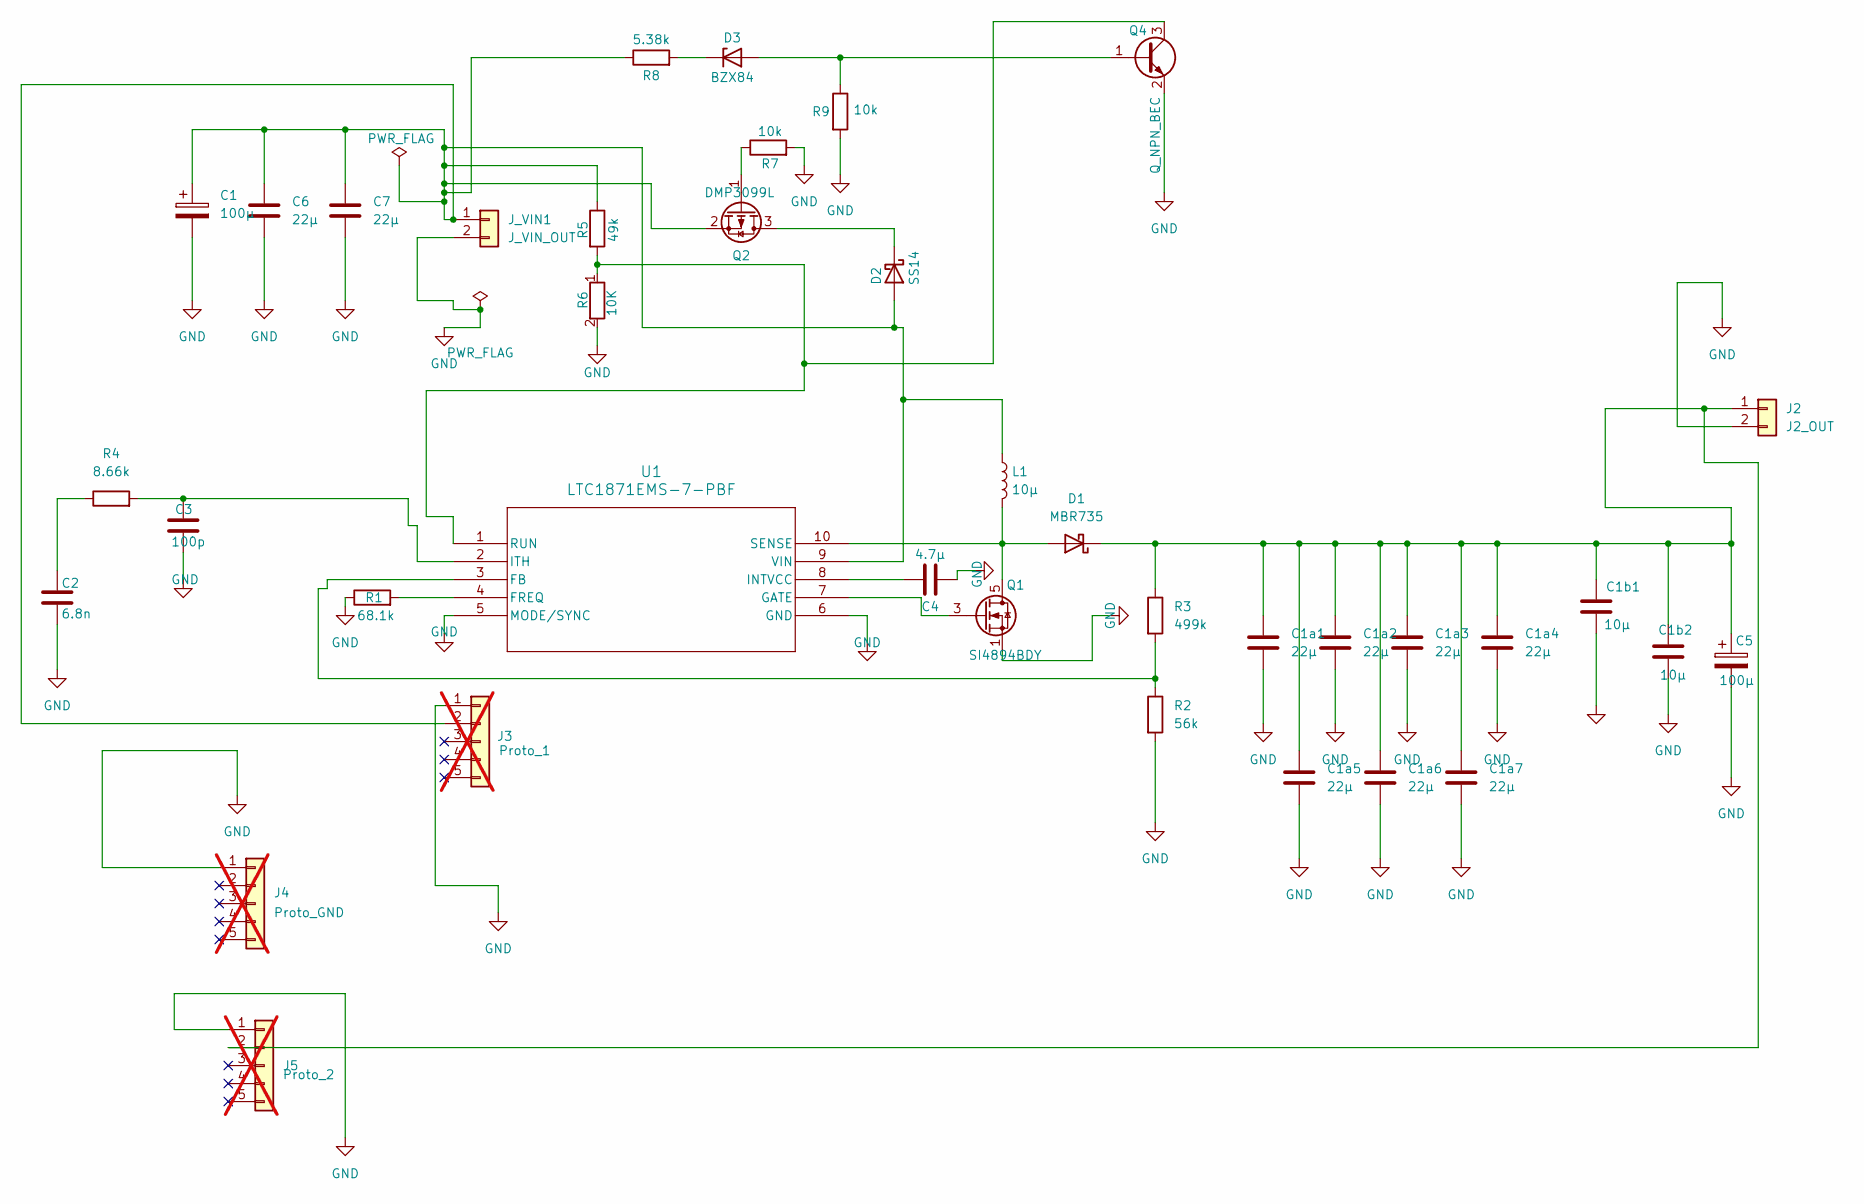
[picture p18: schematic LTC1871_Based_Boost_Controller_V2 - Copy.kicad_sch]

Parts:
C1, C5: 100µ; CP_Radial_D8.0mm_P3.50mm
C1a1, C1a2, C1a3, C1a4, C1a5, C1a6, C1a7, C6, C7: 22µ; C_1206_3216Metric
C1b1, C1b2: 10µ; C_0805_2012Metric
C2: 6.8n; C_0805_2012Metric
C3: 100p; C_0805_2012Metric
C4: 4.7µ; C_0805_2012Metric
D1: MBR735; TO-220-2_Vertical
D2: SS14; D_SMA
D3: BZX84; SOT-23
J2: J2_OUT; PinHeader_1x02_P2.54mm_Vertical
J3: Proto_1; PinHeader_1x05_P2.54mm_Vertical; not fitted
J4: Proto_GND; PinHeader_1x05_P2.54mm_Vertical; not fitted
J5: Proto_2; PinHeader_1x05_P2.54mm_Vertical; not fitted
J_VIN1: J_VIN_OUT; PinHeader_1x02_P2.54mm_Vertical
L1: 10µ; L_Coilcraft_XAL6060-XXX
Q1: SI4894BDY; SOIC-8_3.9x4.9mm_P1.27mm
Q2: DMP3099L; SOT-23
Q4: Q_NPN_BEC; SOT-23
R1: 68.1k; R_0805_2012Metric
R2: 56k; R_0805_2012Metric
R3: 499k; R_0805_2012Metric
R4: 8.66k; R_0805_2012Metric
R5: 49k; R_0805_2012Metric
R6: 10K; R_0805_2012Metric
R7: 10k; R_0805_2012Metric
R8: 5.38k; R_0402_1005Metric
R9: 10k; R_0402_1005Metric
U1: LTC1871EMS-7-PBF; MSOP-10_3x3mm_P0.5mm

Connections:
GND: C1.2, C1a1.2, C1a2.2, C1a3.2, C1a4.2, C1a5.2, C1a6.2, C1a7.2, C1b1.2, C1b2.2, C2.2, C3.2, C4.2, C5.2, C6.2, C7.2, J2.2, J3.1, J4.1 (Pin_1_1), J5.1, J_VIN1.2, Q1.1 (S), Q1.2 (Source), Q1.4 (Source), Q4.2 (E), R1.1, R2.2, R6.2, R7.2, R9.2, U1.5 (MODE/SYNC), U1.6 (GND)
unnamed: C2.1, R4.1
unnamed: D1.2 (A), L1.2, Q1.5 (D), Q1.6 (Drain), Q1.7 (Drain), Q1.8 (Drain), U1.10 (SENSE)
unnamed: C1a1.1, C1a2.1, C1a3.1, C1a4.1, C1a5.1, C1a6.1, C1a7.1, C1b1.1, C1b2.1, C5.1, D1.1 (K), J2.1, J5.2, R3.1
unnamed: C1.1, C6.1, C7.1, D2.2 (A), J3.2, J_VIN1.1, L1.1, Q2.2 (S), R5.1, R8.1, U1.9 (VIN)
unnamed: D2.1 (K), Q2.3 (D)
unnamed: D3.2 (A), Q4.1 (B), R9.1
unnamed: D3.1 (K), R8.2
unnamed: Q1.3 (G), U1.7 (GATE)
unnamed: Q2.1 (G), R7.1
unnamed: Q4.3 (C), R5.2, R6.1, U1.1 (RUN)
unnamed: R2.1, R3.2, U1.3 (FB)
unnamed: R1.2, U1.4 (FREQ)
unnamed: C4.1, U1.8 (INTVCC)
unnamed: C3.1, R4.2, U1.2 (ITH)

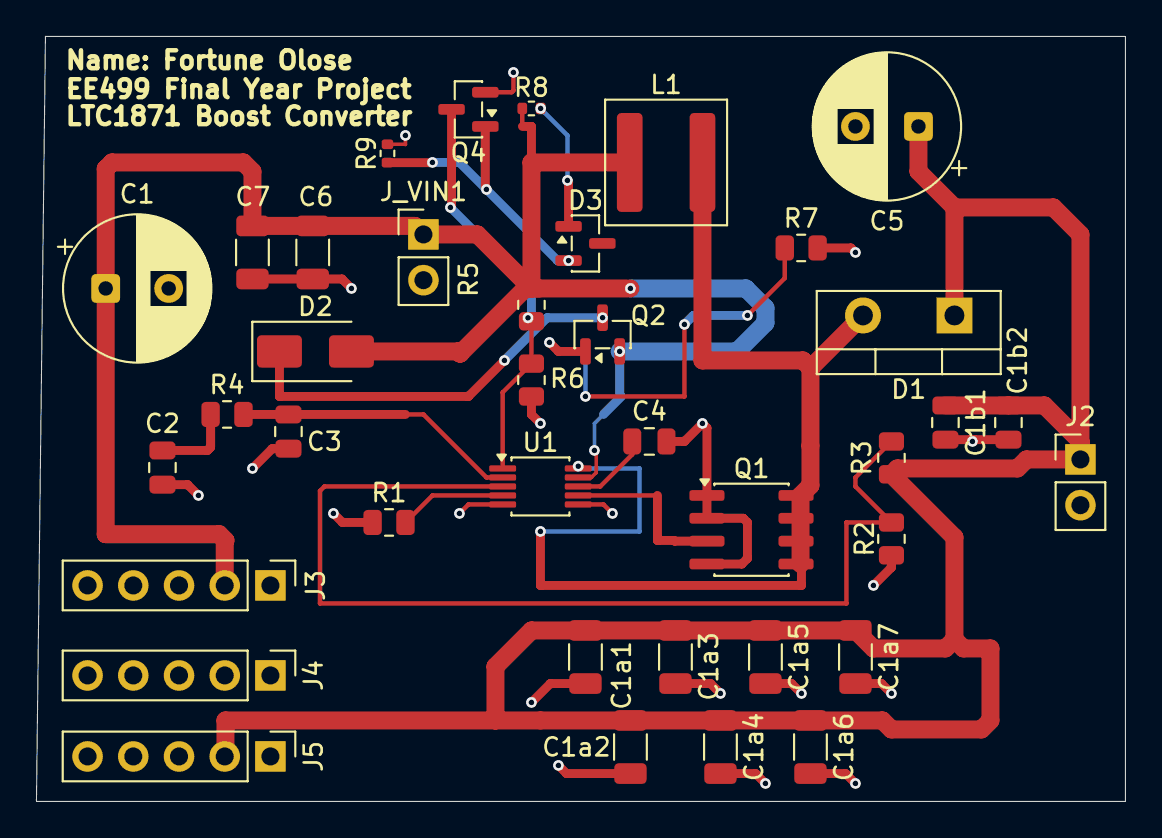
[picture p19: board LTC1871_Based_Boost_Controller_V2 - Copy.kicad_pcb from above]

Board: 2 copper layers, 60.5 x 42.5 mm, 38 parts (0 on the bottom side), 15 nets.

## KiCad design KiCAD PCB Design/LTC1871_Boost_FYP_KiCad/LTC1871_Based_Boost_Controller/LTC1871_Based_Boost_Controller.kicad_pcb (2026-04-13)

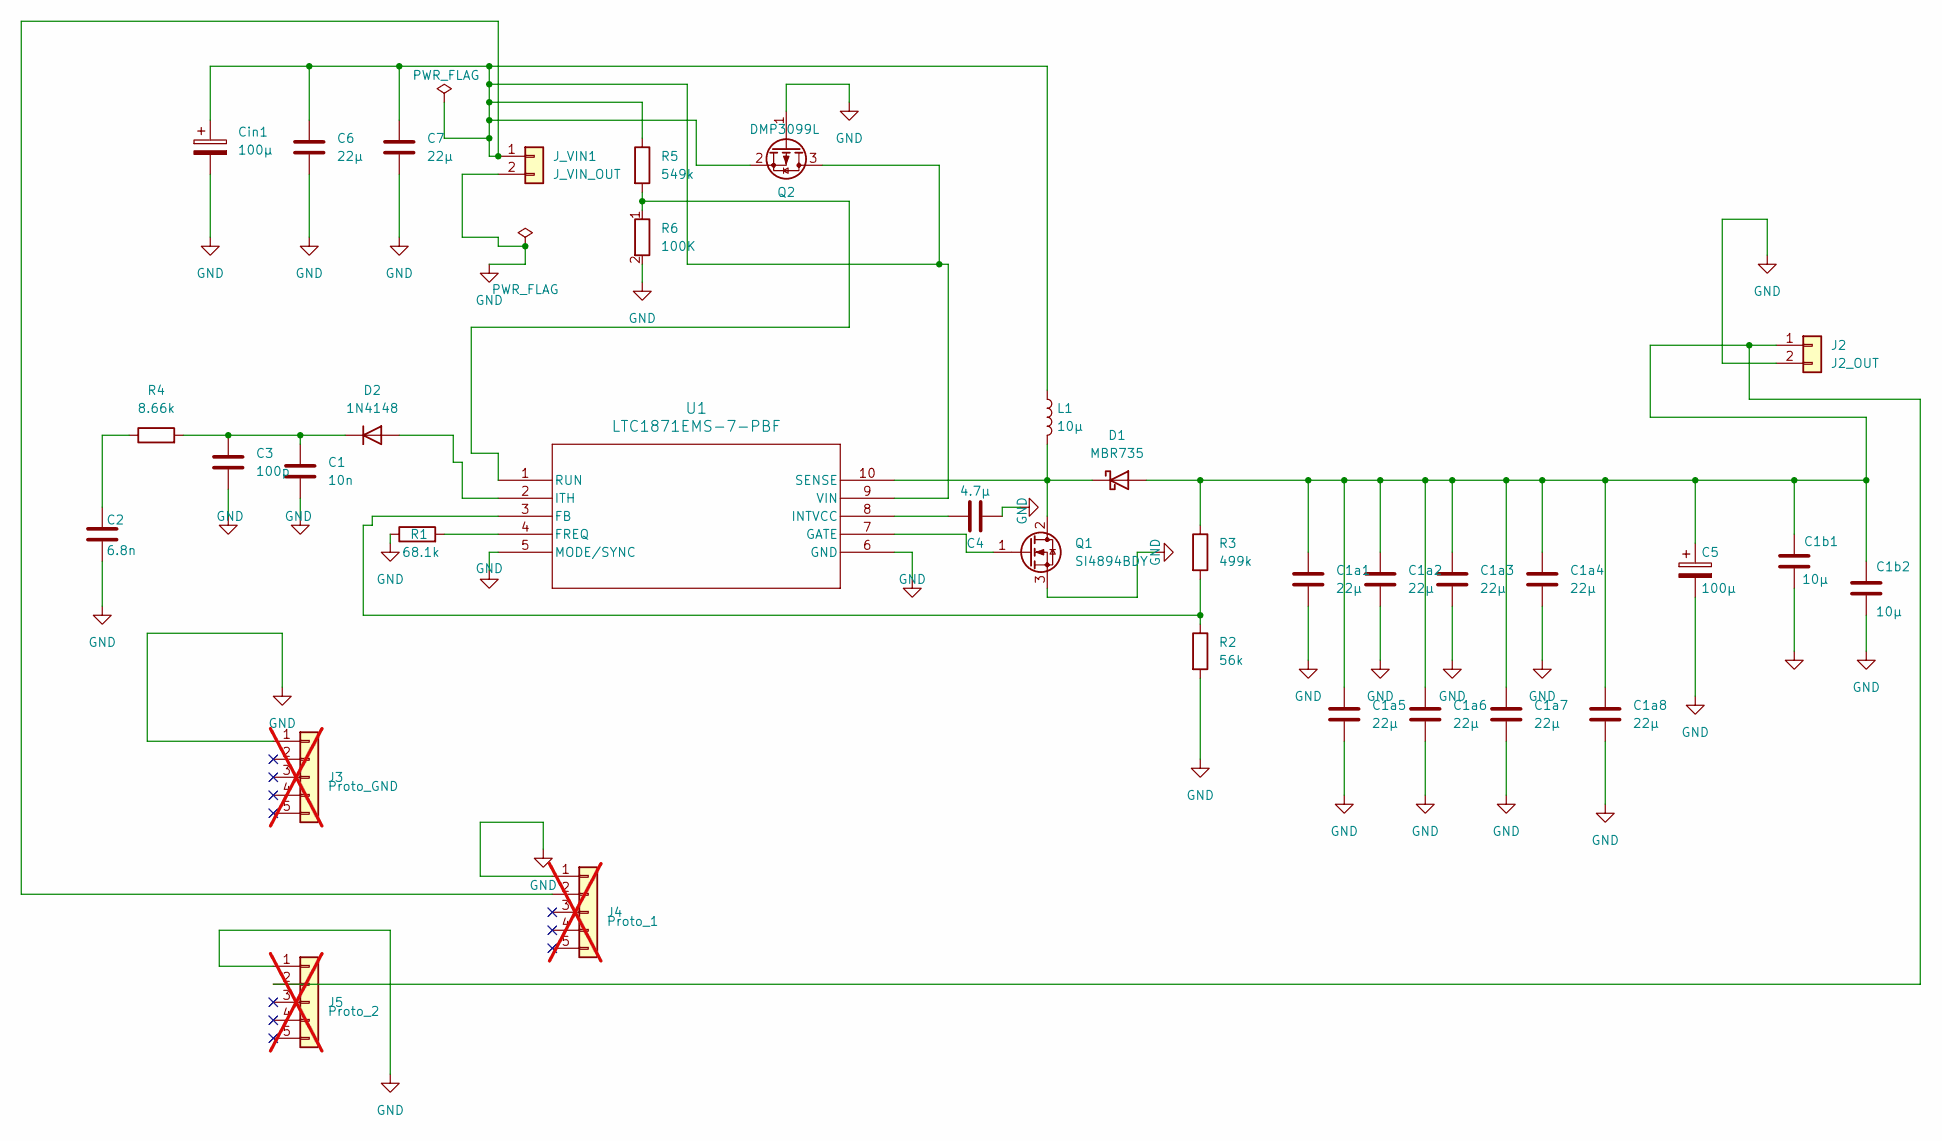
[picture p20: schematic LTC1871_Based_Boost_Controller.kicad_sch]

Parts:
C1: 10n; C_0805_2012Metric
C1a1, C1a2, C1a3, C1a4, C1a5, C1a6, C1a7, C1a8, C6, C7: 22µ; C_1206_3216Metric
C1b1, C1b2: 10µ; C_0805_2012Metric
C2: 6.8n; C_0805_2012Metric
C3: 100p; C_0805_2012Metric
C4: 4.7µ; C_0805_2012Metric
C5: 100µ; CP_Radial_D8.0mm_P3.50mm
Cin1: 100µ; CP_Radial_D8.0mm_P3.50mm
D1: MBR735; D_DO-201AD_P15.24mm_Horizontal
D2: 1N4148; D_SOD-323_HandSoldering
J2: J2_OUT; PinHeader_1x02_P2.54mm_Vertical
J3: Proto_GND; PinHeader_1x05_P2.54mm_Vertical; not fitted
J4: Proto_1; PinHeader_1x05_P2.54mm_Vertical; not fitted
J5: Proto_2; PinHeader_1x05_P2.54mm_Vertical; not fitted
J_VIN1: J_VIN_OUT; PinHeader_1x02_P2.54mm_Vertical
L1: 10µ; L_Coilcraft_XAL6060-XXX
Q1: SI4894BDY; SOIC-8_3.9x4.9mm_P1.27mm
Q2: DMP3099L; SOT-23
R1: 68.1k; R_0805_2012Metric
R2: 56k; R_0805_2012Metric
R3: 499k; R_0805_2012Metric
R4: 8.66k; R_0805_2012Metric
R5: 549k; R_0805_2012Metric
R6: 100K; R_0805_2012Metric
U1: LTC1871EMS-7-PBF; MSOP-10_3x3mm_P0.5mm

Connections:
GND: C1.2, C1a1.2, C1a2.2, C1a3.2, C1a4.2, C1a5.2, C1a6.2, C1a7.2, C1a8.2, C1b1.2, C1b2.2, C2.2, C3.2, C4.2, C5.2, C6.2, C7.2, Cin1.2, J2.2, J3.1 (Pin_1_1), J4.1, J5.1, J_VIN1.2, Q1.3 (S), Q2.1 (G), R1.1, R2.2, R6.2, U1.5 (MODE/SYNC), U1.6 (GND); also elsewhere on the board
unnamed 1: C2.1, R4.1; also elsewhere on the board
unnamed: C1a1.1, C1a2.1, C1a3.1, C1a4.1, C1a5.1, C1a6.1, C1a7.1, C1a8.1, C1b1.1, C1b2.1, C5.1, D1.2 (A), J2.1, J5.2, R3.1
unnamed: D1.1 (K), L1.2, Q1.2 (D), Q1.4 (Drain), Q1.5 (Drain), Q1.6 (Drain), Q1.7 (Drain), Q1.8 (Drain), U1.10 (SENSE)
unnamed: D2.2 (A), U1.2 (ITH)
unnamed: C1.1, C3.1, D2.1 (K), R4.2
unnamed: C6.1, C7.1, Cin1.1, J4.2, J_VIN1.1, L1.1, Q2.2 (S), Q2.3 (D), R5.1, U1.9 (VIN)
unnamed: Q1.1 (G), U1.7 (GATE)
unnamed: R2.1, R3.2, U1.3 (FB)
unnamed: R1.2, U1.4 (FREQ)
unnamed: C4.1, U1.8 (INTVCC)
unnamed: R5.2, R6.1, U1.1 (RUN)

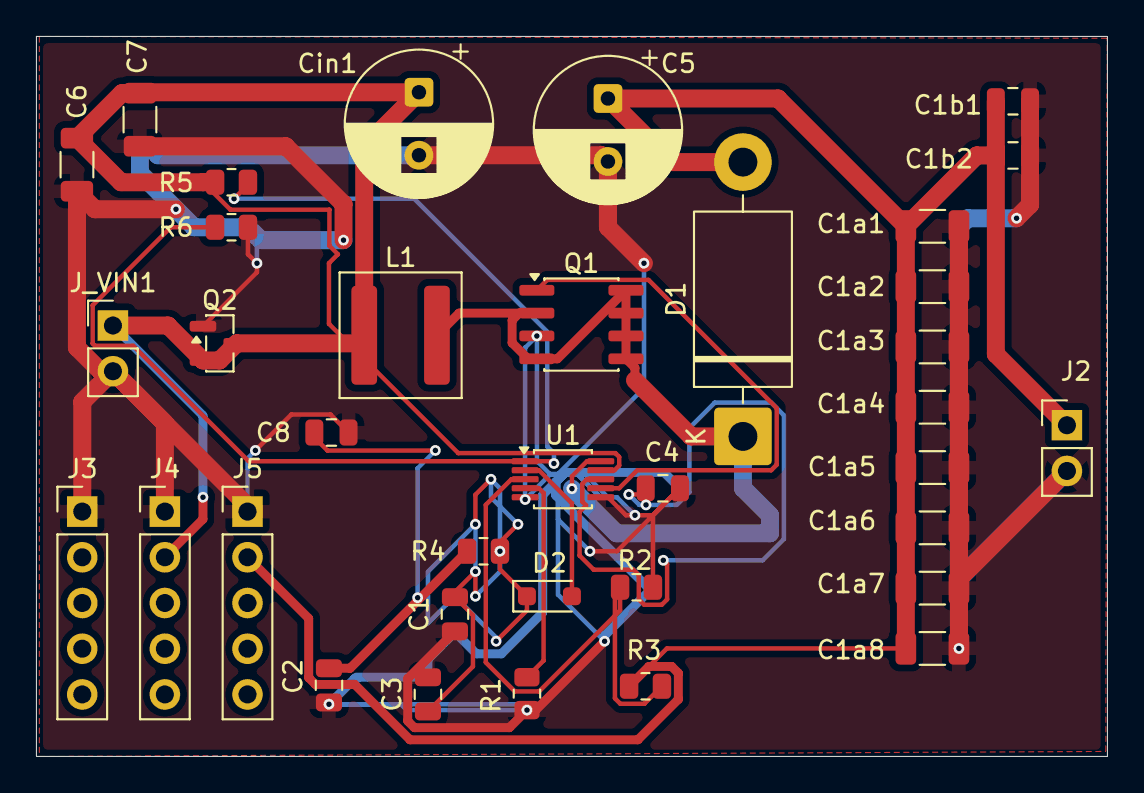
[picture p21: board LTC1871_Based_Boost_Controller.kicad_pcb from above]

Board: 2 copper layers, 59.5 x 40.0 mm, 36 parts (0 on the bottom side), 12 nets.

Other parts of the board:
C8: 220n; C_0805_2012Metric

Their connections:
GND: C8.2; also elsewhere on the board
unnamed 1: C8.1; also elsewhere on the board

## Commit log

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2026-04-05 Add LTC1871 KiCad PCB design files
    [LTC1871_Based_Boost_Controller.kicad_pcb, LTC1871_Based_Boost_Controller.kicad_sch]
2026-04-06 Auto-sync from Fortune at 2026-04-07 00:22:32
    [LTC1871_Based_Boost_Controller.kicad_pcb, LTC1871_Based_Boost_Controller.kicad_sch]
2026-04-08 Auto-sync from Fortune at 2026-04-08 13:10:18
    [LTC1871_Based_Boost_Controller.kicad_pcb, LTC1871_Based_Boost_Controller.kicad_sch]
2026-04-08 Auto-sync from Fortune at 2026-04-08 13:28:10
    [LTC1871_Based_Boost_Controller.kicad_sch]
2026-04-08 Auto-sync from Fortune at 2026-04-08 16:47:45
    [LTC1871_Based_Boost_Controller.kicad_pcb]
2026-04-08 Auto-sync from Fortune at 2026-04-08 19:32:21
    [LTC1871_Based_Boost_Controller.kicad_sch]
2026-04-08 Auto-sync from Fortune at 2026-04-08 21:36:22
    [LTC1871_Based_Boost_Controller.kicad_pcb]
2026-04-08 Auto-sync from Fortune at 2026-04-08 21:37:35
    [LTC1871_Based_Boost_Controller.kicad_sch]
2026-04-08 Auto-sync from Fortune at 2026-04-08 21:38:57
    [LTC1871_Based_Boost_Controller.kicad_pcb]
2026-04-08 Auto-sync from Fortune at 2026-04-08 23:37:36
    [LTC1871_Based_Boost_Controller.kicad_pcb]
2026-04-08 Auto-sync from Fortune at 2026-04-08 23:49:32
    [LTC1871_Based_Boost_Controller.kicad_pcb, LTC1871_Based_Boost_Controller.kicad_sch]
2026-04-09 Auto-sync from Fortune at 2026-04-09 08:51:17
    [LTC1871_Based_Boost_Controller.kicad_pcb]
2026-04-09 Auto-sync from Fortune at 2026-04-09 18:59:21
    [LTC1871_Based_Boost_Controller.kicad_pcb, LTC1871_Based_Boost_Controller.kicad_sch]
2026-04-09 Auto-sync from Fortune at 2026-04-09 20:51:06
    [LTC1871_Based_Boost_Controller.kicad_pcb]
2026-04-09 Auto-sync from Fortune at 2026-04-10 00:15:56
    [LTC1871_Based_Boost_Controller.kicad_pcb, LTC1871_Based_Boost_Controller.kicad_sch]
2026-04-10 Auto-sync from Fortune at 2026-04-10 15:43:13
    [LTC1871_Based_Boost_Controller.kicad_pcb, LTC1871_Based_Boost_Controller.kicad_sch]
2026-04-10 Auto-sync from Fortune at 2026-04-10 17:12:48
    [LTC1871_Based_Boost_Controller-B_Cu.gbl, LTC1871_Based_Boost_Controller-B_Mask.gbs, LTC1871_Based_Boost_Controller-B_Paste.gbp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]
2026-04-10 Auto-sync from Fortune at 2026-04-10 17:22:10
    [LTC1871_Based_Boost_Controller.csv]
2026-04-10 Auto-sync from Fortune at 2026-04-10 17:23:14
    [LTC1871_Based_Boost_Controller.csv]
2026-04-10 Auto-sync from Fortune at 2026-04-10 17:58:44
    [LTC1871_Based_Boost_Controller.kicad_pcb]
2026-04-11 Auto-sync from Fortune at 2026-04-11 22:57:18
    [LTC1871_Based_Boost_Controller.kicad_pcb, LTC1871_Based_Boost_Controller.kicad_sch]
2026-04-13 Auto-sync from Fortune at 2026-04-13 06:50:55
    [LTC1871_Based_Boost_Controller.kicad_sch]
2026-04-13 Auto-sync from Fortune at 2026-04-13 21:30:20
    [LTC1871_Based_Boost_Controller.kicad_pcb, LTC1871_Based_Boost_Controller_V2.kicad_pcb, LTC1871_Based_Boost_Controller_V2.kicad_sch]
2026-04-13 Auto-sync from Fortune at 2026-04-13 22:49:59
    [LTC1871_Based_Boost_Controller_V2.kicad_pcb]
2026-04-13 Auto-sync from Fortune at 2026-04-13 23:12:01
    [LTC1871_Based_Boost_Controller_V2.kicad_pcb]
2026-04-13 Auto-sync from Fortune at 2026-04-13 23:20:11
    [LTC1871_Based_Boost_Controller_V2.kicad_pcb]
2026-04-14 Auto-sync from Fortune at 2026-04-14 15:01:52
    [LTC1871_Based_Boost_Controller_V2.kicad_pcb]
2026-04-14 Auto-sync from Fortune at 2026-04-14 15:35:52
    [LTC1871_Based_Boost_Controller_V2.kicad_pcb]
2026-04-15 Auto-sync from Fortune at 2026-04-15 19:20:39
    [LTC1871_Based_Boost_Controller_V2-B_Cu.gbr, LTC1871_Based_Boost_Controller_V2-B_Mask.gbr, LTC1871_Based_Boost_Controller_V2-B_Paste.gbr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]
2026-04-18 Auto-sync from Fortune at 2026-04-18 21:09:09
    [LTC1871_Based_Boost_Controller_V2.kicad_pcb, LTC1871_Based_Boost_Controller_V2.kicad_sch]
2026-04-19 Auto-sync from Fortune at 2026-04-19 09:47:09
    [LTC1871_Based_Boost_Controller_V2.kicad_pcb, LTC1871_Based_Boost_Controller_V2.kicad_sch]
2026-04-20 Auto-sync from Fortune at 2026-04-20 05:29:32
    [LTC1871_Based_Boost_Controller_V2-B_Cu.gbr, LTC1871_Based_Boost_Controller_V2-B_Mask.gbr, LTC1871_Based_Boost_Controller_V2-B_Paste.gbr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]
2026-04-20 Auto-sync from Fortune at 2026-04-20 06:51:06
    [LTC1871_Based_Boost_Controller_V2.kicad_pcb]
2026-04-22 Auto-sync from EECR-HN3V674 at 2026-04-22 19:15:57
    [LTC1871_Based_Boost_Controller_V2.kicad_sch]
2026-04-22 Auto-sync from Fortune at 2026-04-23 00:30:17
    [LTC1871_Based_Boost_Controller_V2.kicad_sch]
2026-04-23 Auto-sync from Fortune at 2026-04-23 08:24:03
    [LTC1871_Based_Boost_Controller_V2.kicad_pcb]
2026-04-23 Auto-sync from EECR-HN3V674 at 2026-04-23 21:03:28
    [LTC1871_Based_Boost_Controller_V2 - Copy.kicad_pcb, LTC1871_Based_Boost_Controller_V2 - Copy.kicad_sch, LTC1871_Based_Boost_Controller_V2.csv]
2026-04-24 Auto-sync from Fortune at 2026-04-24 10:23:43
    [LTC1871_Based_Boost_Controller_V2 - Copy.kicad_pcb]
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
